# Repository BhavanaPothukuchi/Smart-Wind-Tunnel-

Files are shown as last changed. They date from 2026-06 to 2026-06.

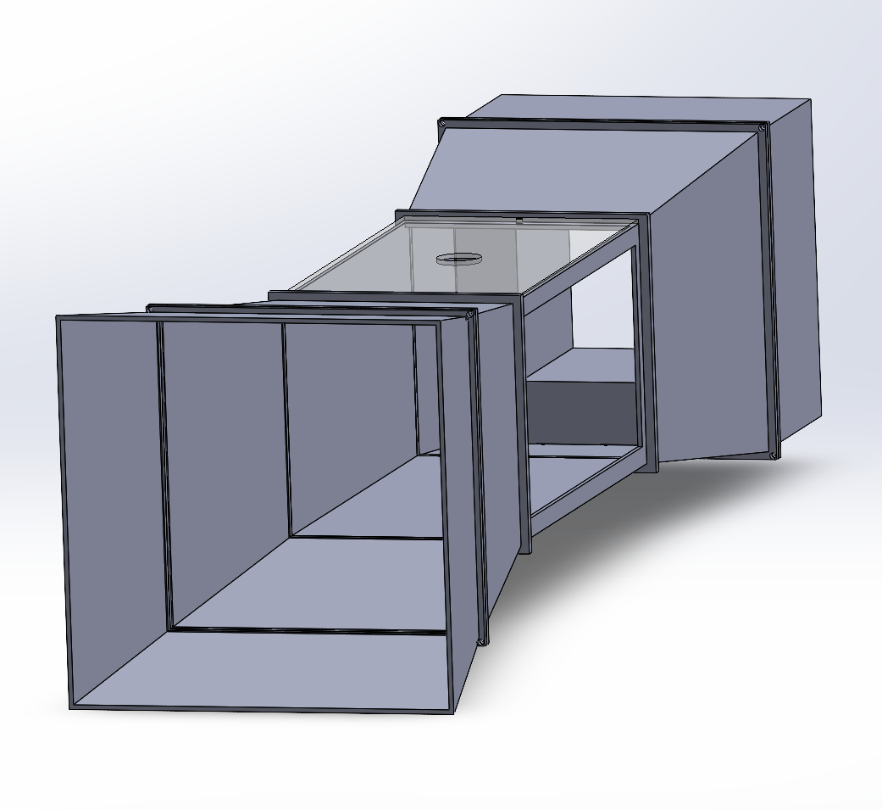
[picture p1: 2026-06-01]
hardware/CAD/Assembly images/Assembly Image 3 bp.png

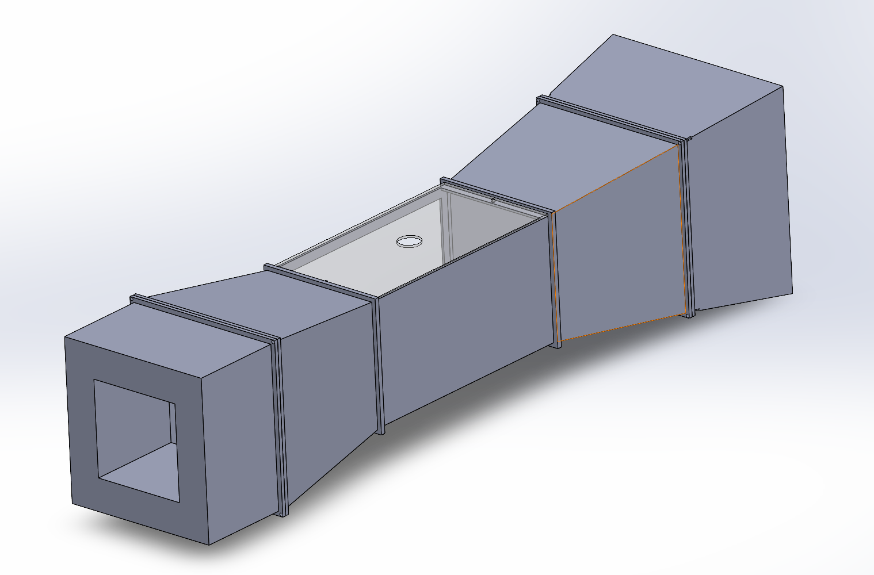
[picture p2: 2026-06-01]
hardware/CAD/Assembly images/Assembly Image 4 bp.png

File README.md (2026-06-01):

# Smart Wind Tunnel
 
**A fully instrumented subsonic wind tunnel designed from scratch in SolidWorks,
3D printed, and connected to a live aerodynamic data acquisition dashboard.**
 
Demo video coming soon, currently in fabrication_

---
 
## What is this?
 
A benchtop wind tunnel that measures real aerodynamic forces and airspeed in real time, displays them on a live web dashboard, and validates results against published NACA 0012 airfoil data.
 
Built as an independent engineering project to physically validate CFD simulation work (STAR-CCM+) with real sensor data closing the loop between computational and experimental aerodynamics. Every part of the system was built from scratch: mechanical structure, sensor wiring, embedded firmware, and the full software stack.
 
---
 
## Features
 
| Feature | Description |
|---|---|
|  📊 **Live dashboard** | Real-time velocity, drag force, Reynolds number, and Cd — updating every 100ms |
|  🌫️ **Flow visualization** | Fog machine at the inlet makes airflow patterns and separation visible on camera |
|  📁 **Session logging** | Every test run saved automatically with timestamp and angle of attack |
|  📈 **Validation** | Drag polar compared against published NACA 0012 data at Re ≈ 100,000 |
|  🔧 **Modular design** | Flanged joints let you swap tunnel sections, airfoil models, and sensors |
 
---
 
## How the whole system works
 
```
                     Both sensors live inside here 
                  ↓                                  ↓
[Bell Mouth] → [Contraction] → [Test Section] → [Diffuser] → [Fan]
                                  ↑         ↑
                             Pitot tube  Load cell
                             (airspeed) (drag force)
                                  ↓         ↓
                                       ↓
                               Arduino Uno R3
                         (reads sensors 10x/sec,
                          sends to Pi over USB)
                                       ↓
                               Raspberry Pi 5
                          (runs Python, does math,
                           broadcasts over WiFi)
                                       ↓
                             FastAPI + WebSocket
                          (live data pipeline over
                           your local network)
                                       ↓
                             React Live Dashboard
                          (opens in your browser,
                           updates in real time)
``` 
## Flow Visualization
 
A mini fog machine feeds glycol haze into the bell mouth inlet. Under the right lighting the fog makes the boundary layer, wake, and flow separation point around the airfoil completely visible to your eyes and on camera.
 
This turns every test run into a visual demo clip that actually shows the aerodynamics happening in real time.
 
---
 
## Tunnel Sections
 
| Dimensions | Material |
|---|---|
| Inlet (Bell mouth) | 250×250 → 200×200mm, 150mm long | 3D printed PLA |
| Contraction | 200×200 → 150×150mm, 200mm long | 3D printed PLA |
| Test section | 150×150mm × 300mm | Clear acrylic + 3D printed PLA frame |
| Diffuser | 150×150 → 200×200mm, 200mm long | 3D printed PLA |
| Fan mount | 200×200mm frame, 122×122mm opening | 3D printed PLA |
 
> All sections connect via flanged joints: M3 bolts through 4mm holes in each flange, with foam weatherstrip tape between faces for an airtight seal.
 
---
 
## Tech Stack
 
| Layer | Technology | What it does |
|---|---|---|
| CAD | SolidWorks | All 5 tunnel sections + airfoil modeled from scratch |
| Microcontroller | Arduino Uno R3 | Reads sensors, streams data to Pi over USB |
| Computer | Raspberry Pi 5 (2GB) | Runs Python server, hosts dashboard backend |
| Airspeed sensor | MPXV7002DP | Differential pressure → airspeed via pitot tube |
| Force sensor | HX711 + 1kg load cell | Measures drag force on the airfoil |
| Backend | Python 3 + FastAPI | Processes data, broadcasts live over WiFi |
| Real-time comms | WebSockets | Keeps dashboard live without page refreshes |
| Frontend | React + Recharts | Live dashboard webpage with charts |
| Database | SQLite | Stores every sensor reading with timestamps |
 
---
 
## Hardware & CAD Files
 
Full bill of materials with links and prices → [`hardware/BOM.csv`](hardware/BOM.csv)
**Total build cost: ~$238**

---
 
## Running the Software
 
### On the Raspberry Pi
```bash
cd software/backend
pip install -r requirements.txt
uvicorn backend:app --host 0.0.0.0 --port 8000
```
> Starts the Python server. Pi now listens to Arduino and broadcasts live data over WiFi on port 8000.
 
### On your laptop
```bash
cd software/dashboard
npm install
npm start
```
> Opens the dashboard in your browser. Finds the Pi automatically over WiFi and starts showing live data.
 
---
 
## Build Log
 
Week-by-week progress with photos - [`Build-log.md`](Build-log.md)
 
---
 
## Results
 
Drag polar vs published NACA 0012 data - *coming once fabrication is complete*
 
---

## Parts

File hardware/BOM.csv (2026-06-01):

Item | Description | Qty | Unit Price (USD) | Supplier | Link
Arctic P12 PWM PST 120mm Fan | High static pressure PWM fan for tunnel exit | 1 | $11.99 | Amazon | https://www.amazon.com/dp/B07GJGF56L
CALPALMY (2-Pack) 12x12 Inch Clear Acrylic Sheet 1/8in (3mm) | Laser-cut transparent test section walls | 1 | $14.99 | Amazon | https://www.amazon.com/dp/B0FF9YL31J
Acrylic Bonding Cement with Applicator Bottle 4oz | Chemical weld for acrylic test section - capillary action | 1 | $19.99 | Amazon | https://www.amazon.com/dp/B0DS69HMN6
1000pcs M3 Screws Kit M3x6/8/10/12/16/20/25/30mm Black Zinc | Bolts for all flange joints - use M3x16mm for flanges | 1 | $8.99 | Amazon | https://www.amazon.com/dp/B0G7HV64L6
uxcell Foam Seal Tape 30mm Wide x 3mm Thick 5m Pack of 2 | Air seal between flange faces - 32ft total | 1 | $15.89 | Amazon | https://www.amazon.com/dp/B08LCVXYNK
PLA Filament 1kg Black | All 3D printed tunnel sections | 1 | $14.49 | Amazon | https://a.co/d/0dQmE15L
PULACO Mist Maker | makes airflow patterns visible on camera | 1 | $11.99 | Amazon | https://a.co/d/0baV8J35
Raspberry Pi 5 2GB | Mini Linux computer - runs Python backend and live dashboard | 1 | $75.00 | Adafruit | https://www.adafruit.com/product/6007
Official Raspberry Pi 27W USB-C Power Supply | Powers the Raspberry Pi 5 | 1 | $22.72 | Amazon | https://www.amazon.com/dp/B0D2XRWQZL
Arduino Uno R3 (Official) | Reads sensors and streams data to Pi via USB serial | 1 | $27.60 | Arduino Store | https://store-usa.arduino.cc/products/arduino-uno-rev3
MPXV7002DP Differential Pressure Sensor | Airspeed via pitot-static tube | 1 | $22.19 | DigiKey | https://www.digikey.com/en/products/detail/nxp-usa-inc/MPXV7002DP/1168436
NOYITO HX711 + 1kg Load Cell Combo | Drag force measurement - mounts under test section floor | 1 | $6.69 | Amazon | https://www.amazon.com/dp/B07BGRDKG5
uxcell Brass Round Tube 4mm OD 0.5mm Wall 300mm 3pcs | Pitot tube - pokes through test section lid into airflow | 1 | $9.59 | Amazon | https://a.co/d/02yKToq7
Hooshing Silicone Tubing 4mm ID x 6mm OD 10ft | Connects pitot tube ports to MPXV7002DP sensor | 1 | $11.99 | Amazon | https://a.co/d/0gU23gT2
Breadboard + Jumper Wire Kit | No-solder prototyping - all connections plug in | 1 | $16.99 | Amazon | https://www.amazon.com/dp/B0BNH7LYH3
SanDisk Ultra 32GB microSDHC 120MB/s Class 10 UHS-I | Raspberry Pi OS storage - flash with Pi Imager before first boot | 1 | $22.12 | Amazon | https://www.amazon.com/dp/B08L5HMJVW
USB-A to USB-B Cable 2-pack | Connects Arduino Uno to Raspberry Pi | 1 | $6.99 | Amazon | https://www.amazon.com/dp/B09JRXT1TY?psc=1&ref_=cm_sw_r_cp_ud_ct_7FY887B95F0K138WP145_3
ANOSON Zip Ties 400pcs Assorted 4+6+8+12 inch | Cable management inside tunnel and for wiring | 1 | $6.99 | Amazon | https://www.amazon.com/dp/B0C2Z4L3S6?psc=1&ref_=cm_sw_r_cp_ud_ct_7FY887B95F0K138WP145_2
Toolant Allen Wrench Set 26pcs Metric + SAE | Tightens M3 hex socket screws — needs 2.5mm hex key for M3 | 1 | $16.99 | Amazon | https://www.amazon.com/dp/B0FRDS6VFC?psc=1&ref_=cm_sw_r_cp_ud_ct_7FY887B95F0K138WP145_1
TOTAL | $344.19

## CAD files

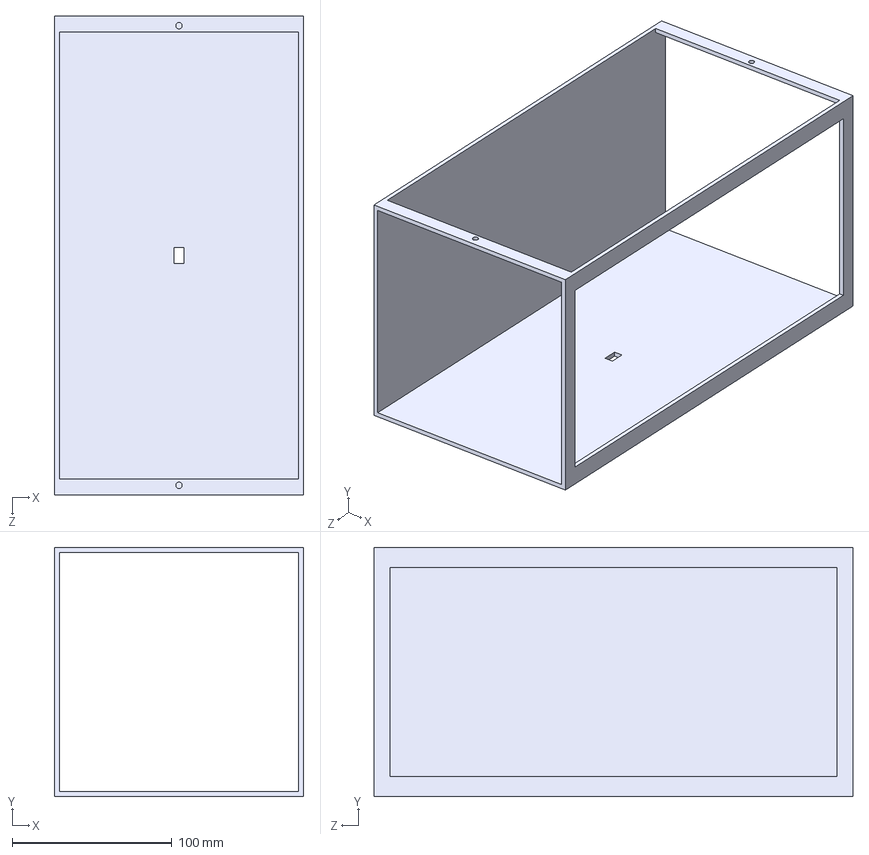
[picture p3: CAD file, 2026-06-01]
hardware/CAD/Load Cell bp.STEP
156.0 x 156.0 x 300.0 mm

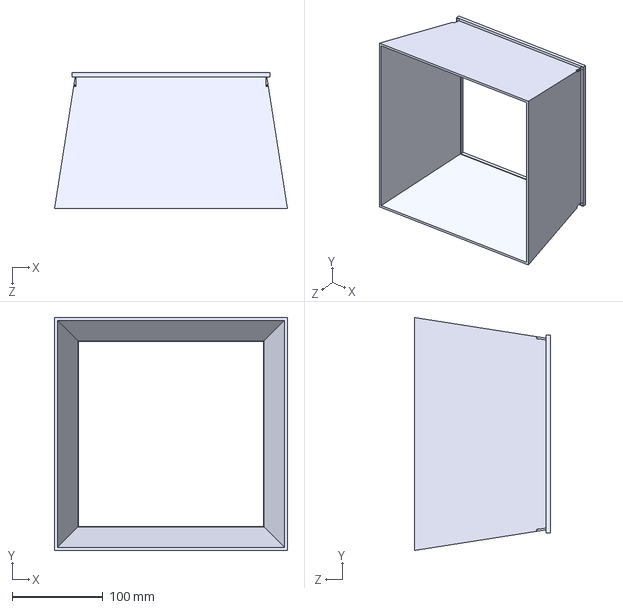
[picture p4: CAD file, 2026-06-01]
hardware/CAD/Inlet bp.STEP
256.1 x 256.1 x 150.0 mm

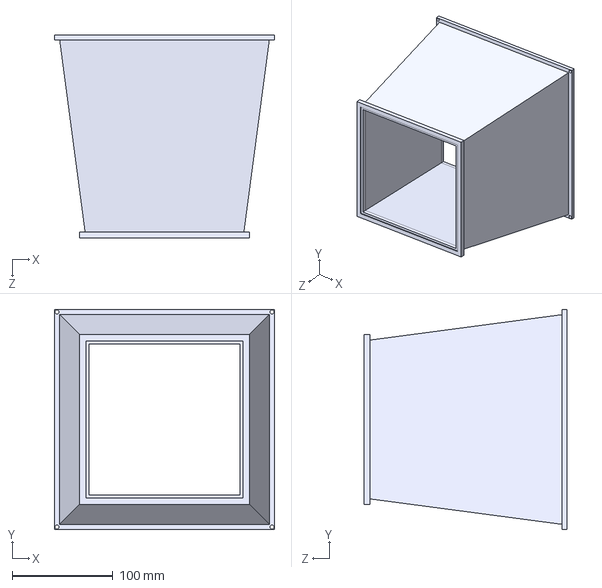
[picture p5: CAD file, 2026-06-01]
hardware/CAD/Contraction and Diffuser bp.STEP
218.0 x 218.0 x 201.0 mm

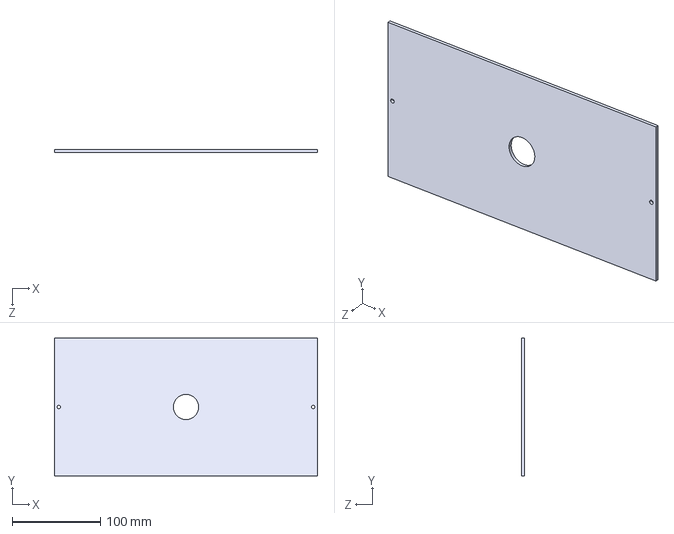
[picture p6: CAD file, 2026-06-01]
hardware/CAD/acrylic top glass bp.STEP
298.0 x 156.0 x 3.00 mm

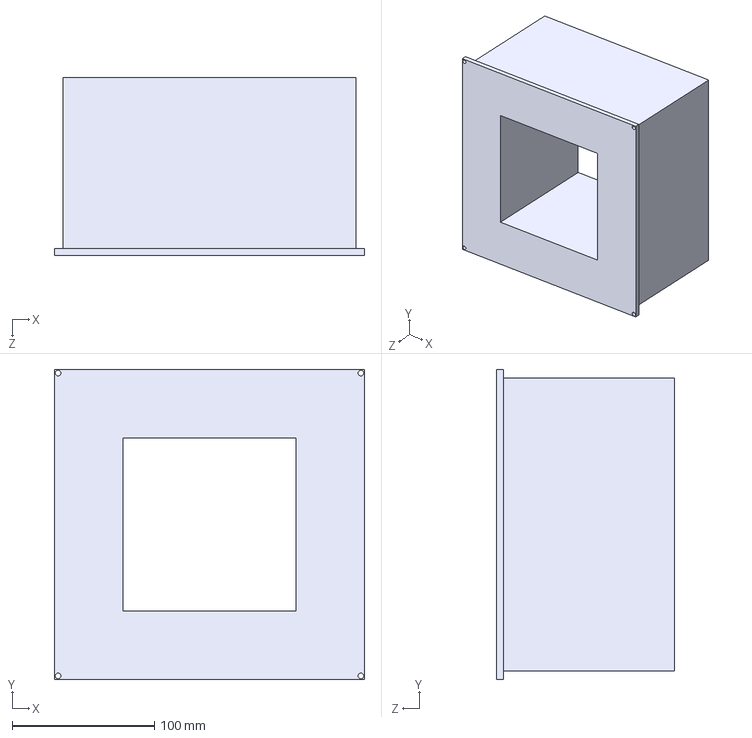
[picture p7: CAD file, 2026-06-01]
hardware/CAD/Fan port bp.STEP
218.0 x 218.0 x 125.0 mm

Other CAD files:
hardware/CAD/Contraction and Diffuser bp.SLDPRT
hardware/CAD/Fan port bp.SLDPRT
hardware/CAD/Inlet bp.SLDPRT
hardware/CAD/Load Cell bp.SLDPRT
hardware/CAD/acrylic top glass bp.SLDPRT

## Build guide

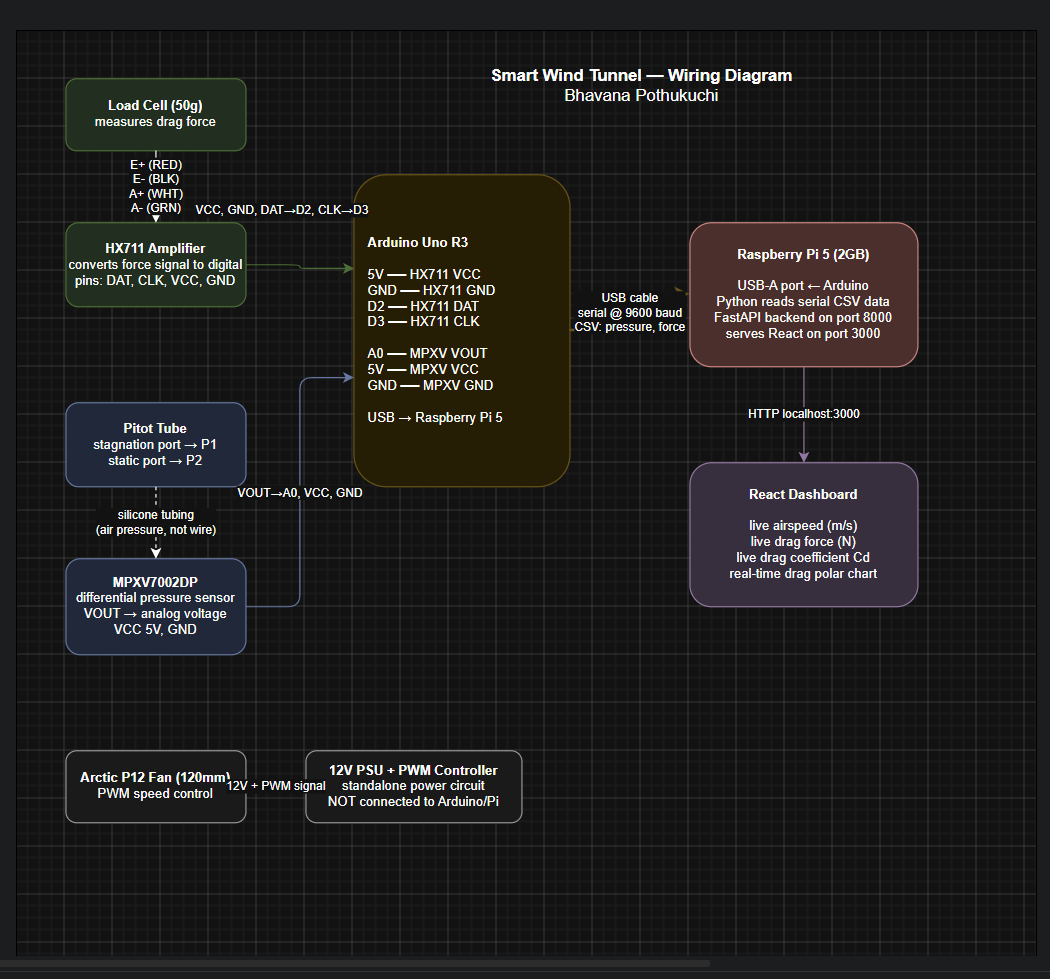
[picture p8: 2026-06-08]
Docs/wiring diagram wind tunnel bp.png

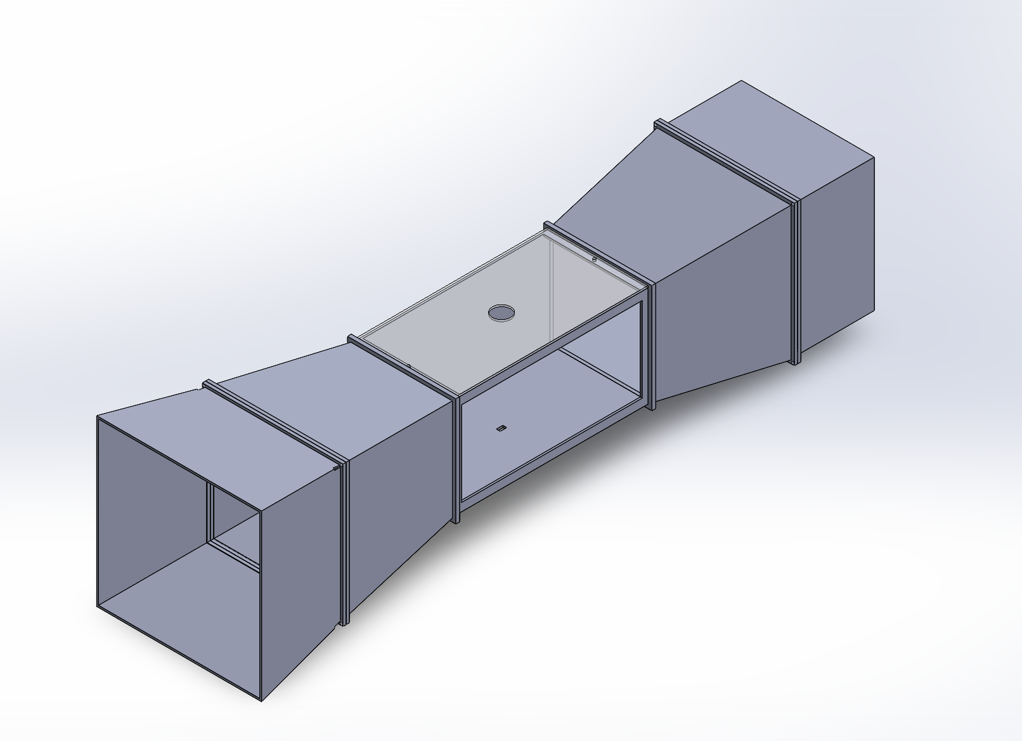
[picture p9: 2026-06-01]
hardware/CAD/Assembly images/Assembly Image 1 bp.png

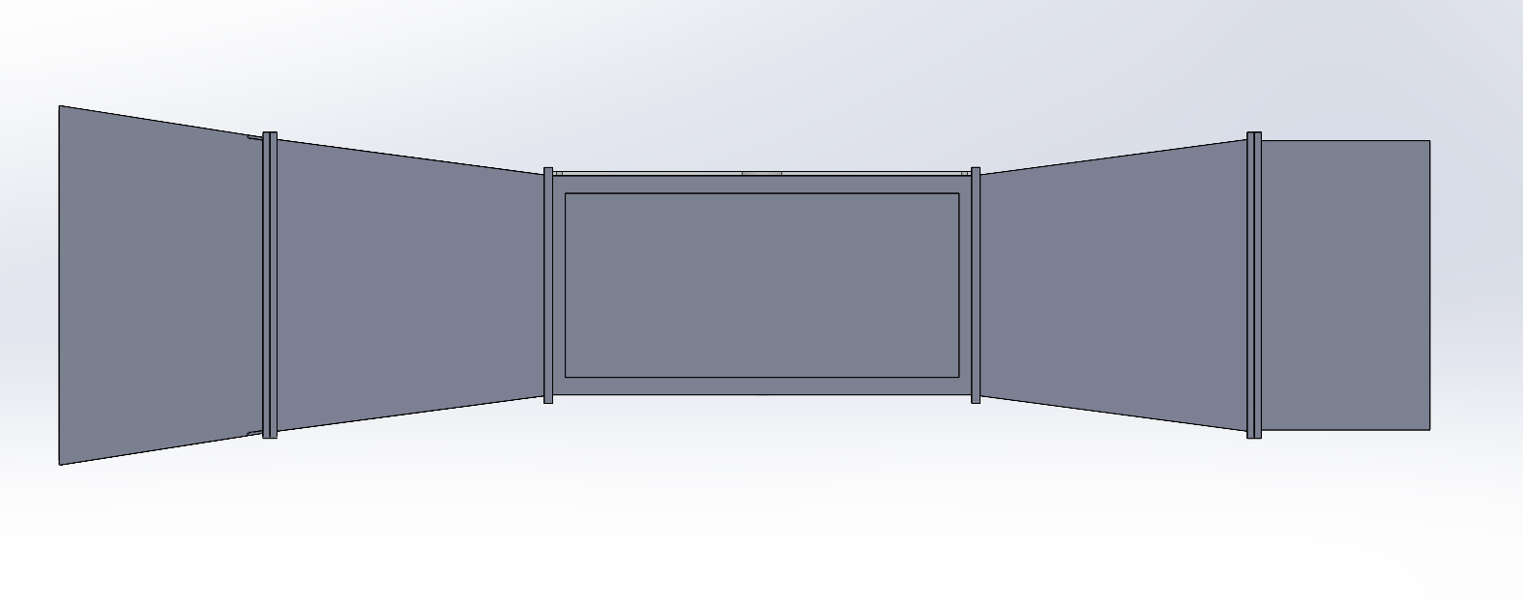
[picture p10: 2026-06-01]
hardware/CAD/Assembly images/Assembly Image 2 bp.png

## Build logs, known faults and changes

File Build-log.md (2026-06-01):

## Week 1 — Research & Design
May/June 2026
- Watched Aki's DIY wind tunnel YouTube series
- Researched tunnel physics
- Downloaded NACA 0012 coordinate data
- Decided on measurements for tunnel section and 120mm fan

## Week 2 — Full CAD in SolidWorks
June 2026
- Modeled all 5 tunnel sections: bell mouth, contraction, test section, diffuser, fan mount
- Added flanged joints with M3 bolt holes (4mm clearance diameter) on all mating faces
- Modeled load cell mount plate and rod
- Created full assembly in SolidWorks

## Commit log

2026-06-01 Create CAD
2026-06-01 Create Inlet CAD
2026-06-08 Create Wiring Diagram
